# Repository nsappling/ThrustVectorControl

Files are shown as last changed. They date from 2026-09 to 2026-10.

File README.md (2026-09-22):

# Interactive Thrust Vector Control Demonstrator

An interactive senior design project that demonstrates how thrust vector control (TVC) can stabilize a rocket-like body.

Instead of combustion, the system uses an electric ducted fan (EDF) mounted on a **single-axis gimbal**. An inertial measurement unit (IMU) measures the rocket's angle, while a feedback controller redirects the thrust to keep the rocket upright.

The final system is intended to become an interactive science-center exhibit for elementary-school students, families, and school groups.

**Project Status:** Active development. The main concept has been selected, but components and design specifications are still being tested and refined.

## Team.  

- Nate Sapp
- Warren Schindler
- Kailash Gupta-Verma
- Alec Garcia

## Project Goals

Here are our goals:
- Demonstrate thrust vector control in a visible and intuitive way.
- Actively stabilize a rocket-like body about one rotational axis.
- Allow visitors to interact with the system using a joystick.
- Provide immediate visual feedback.
- Be understandable without prior engineering knowledge.
- Operate safely and reliably in a public environment.
- Include a brief explanation for visitors interested in the engineering.
    
## Concept Overview

The demonstrator consists of a lightweight rocket-shaped body mounted to a single-axis pivot. The pivot is positioned below the system's center of gravity, making the rocket naturally unstable.

A gimbaled EDF produces thrust along the rocket's body. A servo rotates the EDF about one axis, changing the direction of the thrust and creating a corrective moment about the pivot.

An IMU continuously measures the rocket's angle and angular velocity. A feedback controller compares the measured angle with the desired angle and adjusts the gimbal to move the rocket toward its target orientation.

The user will interact with the system through a joystick. Depending on the final operating mode, the joystick may command a desired rocket angle, change the thrust level, or apply a temporary disturbance.

## How It Works

1. The IMU measures the rocket's angle and angular velocity.
2. The controller compares the measured angle with the desired angle.
3. A feedback algorithm calculates the required correction.
4. A servo rotates the EDF gimbal.
5. The redirected thrust creates a moment about the pivot.
6. The rocket moves toward the desired orientation.
7. The control loop repeats continuously to maintain stability.

The controller error is defined as:

error = desired angle - measured angle

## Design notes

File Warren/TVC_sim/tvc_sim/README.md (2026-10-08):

# 1-DOF Gimbaled-EDF TVC Demonstrator: MATLAB design simulation

Plain MATLAB (R2019b or newer). No toolboxes needed.

## Quick start
1. Open MATLAB in this folder.
2. Run `tvc_main`. It prints the linear design report, then runs the three demo tests (controller OFF, controller ON, human pilot), plots θ, θ̇, δ, and prints the metrics.
3. Run sections of `tvc_design_sweeps` (Ctrl+Enter inside a `%%` block) for the trade studies.
4. Run `tvc_servo_sizing` for the gimbal servo torque/speed check.

## Files
| File | What it does |
|---|---|
| `tvc_params.m` | **Every number in one place.** Each one is tagged `[EST]`, `[SPEC]`, or `[DES]`. |
| `tvc_simulate.m` | Nonlinear plant (RK4) plus discrete IMU, filter, controller, and servo PWM frame |
| `tvc_scenario.m` | Test definitions: push size/timing, mode, throttle, reference angle |
| `tvc_metrics.m` | Settling time, overshoot, max deviation, steady-state error, gimbal saturation, jitter |
| `tvc_design_gains.m` | PD pole placement: `Kp = (wn² + mgh/I)/(TL/I)`, `Kd = 2ζwn/(TL/I)` |
| `tvc_linear_report.m` | Unstable pole, authority ratio, minimum throttle, latency budget, delay margin, human-delay limit |
| `tvc_design_sweeps.m` | Eight trade studies (see the header of the file) |
| `tvc_servo_sizing.m` | Inertia → acceleration → torque → ×2 margin → candidate torque-speed lines |
| `tvc_animate.m` | Side-view animation of any run |
| `edf_thrust.m` | Thrust vs throttle: power law, or your load-cell table |

## Model
```
I θ̈ = T L sin δ + m g h sin θ − bθ̇ − τc sgn θ̇ + τ_stop + τ_push − I_g δ̈
```
* Servo: position loop, then slew limit, velocity lag, torque limit, gimbal hard stop. It only latches a new command once per PWM frame (50 Hz analog vs 200–333 Hz digital).
* EDF: static map plus first-order spool-up. Throttle can be fixed or `@(t)`.
* IMU: gyro with noise and residual bias. Accelerometer specific force at `r_imu`, including the `rα` and `rω²` motion terms and EDF vibration, so the accelerometer-only angle is realistically wrong.
* Complementary filter, low-pass D-term, one-sample compute delay, command clamp.
* Human pilot: delayed, noisy PD with tremor, for the "why TVC needs a computer" comparison.

Not modeled: fan roll torque and rotor gyroscopic torque. In 1-DOF both act about axes the pivot reacts, so they load the bearings but don't move θ. Also not modeled: thrust loss vs gimbal angle and duct aerodynamics.

## Plugging in real data
* **Thrust stand (Nate):** `p.thrust_table = [u T; ...]`, `p.tau_edf` from a throttle-step test.
* **CAD (Alec/mech):** `p.m`, `p.h_cg`, `p.I`, `p.L`, and `p.Ig` from mass properties.
* **IMU bench (Warren):** `p.gyro_bias`, noise densities, and especially `p.accel_vib` measured with the EDF running.
* **Servo:** step-test it and fit `p.servo_kpos`/`p.servo_tau`. Set `p.servo_refresh` to what it actually accepts.

Then compare the `tvc_simulate` output to logged θ, θ̇, δ from the hardware (the project plan's model-vs-experiment requirement).

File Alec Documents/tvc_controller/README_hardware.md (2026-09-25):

# TVC controller: hardware setup and bench test

`tvc_controller.ino` is the Arduino version (SparkFun RedBoard, Uno-compatible) of the AUTO-mode controller in `rocketgimball.m` / `tvc_sim.m`: the same low-pass filter, PID, ±35° saturation, and fan-tilt sign convention.

## System layout

```
 GY-521 (MPU-6050) --I2C--> RedBoard   --PWM--> 20 kg servo --> fan gimbal
                             |    USB
                        Raspberry Pi 5  (logging, tuning; later: joystick / exhibit UI)
```

- **RedBoard: real-time control.** It runs the loop at 500 Hz with steady timing, which the PID math relies on.
- **Pi 5: supervisor only.** It's connected over USB, logs data, and sends gain changes. It doesn't need to be connected for the controller to run. Don't wire the RedBoard's TX/RX pins directly to the Pi's GPIO: the Pi uses 3.3 V and the RedBoard uses 5 V. USB is simpler and safe.

## Wiring

| From | To | Notes |
|---|---|---|
| GY-521 VCC | 5V | The GY-521 has its own 3.3 V regulator. |
| GY-521 GND | GND | |
| GY-521 SDA | SDA pin (next to AREF) | Internally the same as A4. |
| GY-521 SCL | SCL pin (next to AREF) | Internally the same as A5. |
| Servo signal (orange/yellow) | D4 | Set by `SERVO_PIN`. |
| Servo + (red) | **External 6 V supply +** | 5–7.4 V. It needs about 3 A capacity, since stall current is ~2.5 A. |
| Servo – (brown/black) | External supply – | |
| External supply – | RedBoard GND | **Required.** Without a common ground the servo signal has no reference. |

⚠️ **Never power the servo from the RedBoard's 5V pin.** A 20 kg servo can pull amps when it moves. That will brown out or reset the RedBoard, or damage the USB port or the Pi. Use a 6 V BEC, a bench supply, or a 5 V ≥3 A adapter.

Optionally, put a 470–1000 µF capacitor across the servo supply near the servo to absorb current spikes.

## IMU mounting

Mount the GY-521 with its **Z axis along the rocket's long axis**, chip side facing the nose, so tilting in the gimbal plane rotates the board about its X axis.
- If the gimbal plane lines up with the board's Y axis instead, set `IMU_USE_Y_AXIS = true`.
- Mount it firmly on foam tape or standoffs. Fan vibration is the main noise source for the accelerometer.

## Setup

1. Open `tvc_controller.ino` in the Arduino IDE.
2. Board: **Arduino Uno** (the RedBoard is Uno-compatible). Port: the `usbserial` / CH340 one. If the port does not appear, install the CH340 driver from SparkFun.
3. Check the settings at the top of the sketch:
   - `SERVO_RANGE_DEG`: 180 or 270, depending on your MIUZEI model.
   - `GIMBAL_RATIO`: 1.0 if the servo horn drives the gimbal directly.
4. Upload, then open Serial Monitor at 115200 baud with line ending set to "Newline". Hold the IMU **upright and still** for about 2 s while it calibrates.

## Bench test (no fan): tilt the IMU by hand to fake the body angle

Do these checks **in order**. Keep the fan unpowered.

1. **Angle sign.** Tip the IMU so the rocket's nose leans RIGHT. `theta_deg` should go **positive**, matching MATLAB's convention. If it goes negative, set `IMU_SIGN = -1.0`.
2. **Servo center.** Send `center`. The fan should point straight along the body. If it doesn't, adjust with `trim 20` (µs; try ±values) or re-seat the servo horn. Send `run` to resume.
3. **Servo direction (the critical one).** Lean the nose RIGHT. The fan's **exhaust should swing LEFT**, pointing opposite to the lean. That pushes the tail right and brings the nose back upright. If the exhaust swings the same way as the lean, set `SERVO_DIR = -1.0`. A wrong sign here is positive feedback, and the real rocket will slam into its stops.
4. **Response.** Tip it quickly and hold it. The fan should snap toward full correction. Hold at ~10° for a few seconds: the fan tilt slowly grows as the integral term builds, then caps at ±35°. This is expected, because in the bench test the servo can't actually push the IMU back upright.
5. **Noise.** Hold it still and upright. The fan should sit near 0° with small jitter. Large chatter means you should lower Kd or raise `tau`.

## Tuning from the Pi (or a laptop)

```bash
pip install pyserial
python3 tvc_logger.py
```

Type commands such as `kp 0.5`, `kd 0.035`, `tau 0.02`, `zero`, `center`, `run`, or `help`. They take effect immediately, but aren't saved when the board powers off. Copy any gains you settle on into the sketch.

Each run is saved as `tvc_log_YYYYMMDD_HHMMSS.csv`. To load a log in MATLAB and compare it to the simulation:

```matlab
d = readtable('tvc_log_....csv');
plot(d.t_ms/1000, d.theta_filt_deg)
```

## Differences from the MATLAB sim

| | MATLAB | RedBoard | Why |
|---|---|---|---|
| Angle measurement | `theta + noise` | Complementary filter of gyro + accel (`COMP_TAU` = 0.5 s) | A real sensor needs fusion: the accelerometer is noisy, and the gyro drifts. |
| Loop rate | 2000 Hz physics step | 500 Hz control loop | The gains transfer unchanged because the PID math uses `dt` explicitly. |
| Integral | No limit | Anti-windup: stops growing while the servo is pinned at its limit | Bench testing holds large errors for seconds at a time. |
| Safety | Mechanical stops | Servo centers if the angle is past 45° (resumes automatically below 35°) or the IMU read fails | |
| Servo | Instant | Servo pulse updates at 50 Hz, plus the servo's own speed | Worth adding a servo lag to `tvc_sim.m` later. |

## Before running with the fan

- Measure the real `F_t`, `R`, `m`, and `r_0`. Re-run `tune_pid.m` with those values, then put the new gains in the sketch.
- Secure the fan and add a guard. Have a physical kill switch on the EDF power.

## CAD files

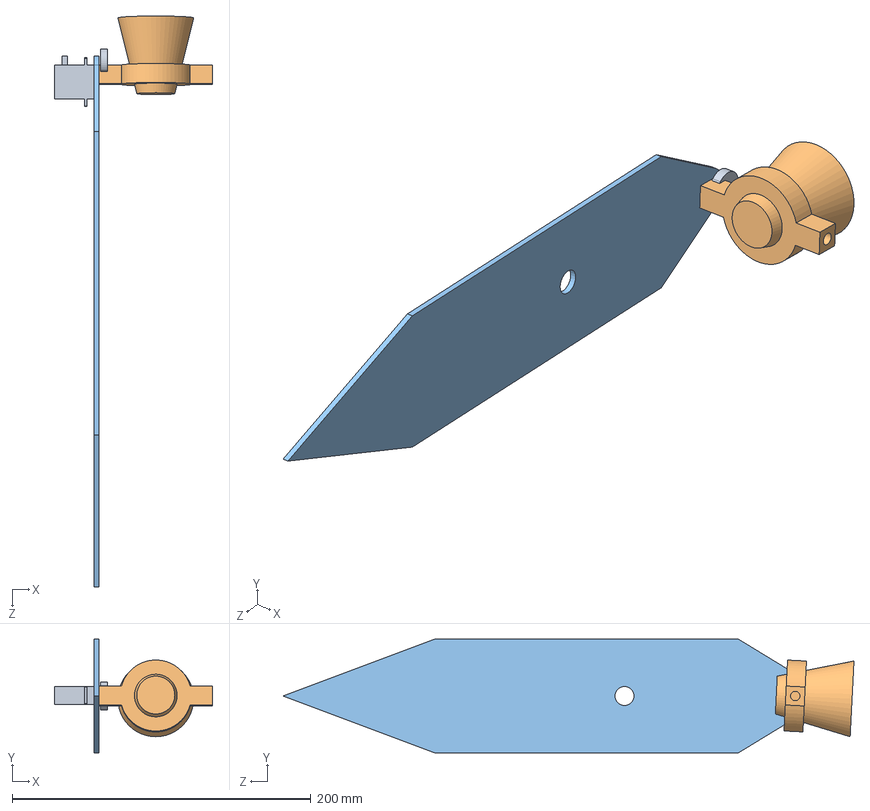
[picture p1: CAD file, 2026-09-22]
Alec Documents/FlatRocketPrototype.SLDASM
106.0 x 76.2 x 382.2 mm
RocketPrototypeFlatBodyPlate
RocketFanforFlatBodyPrototype
BlubirdServocopy

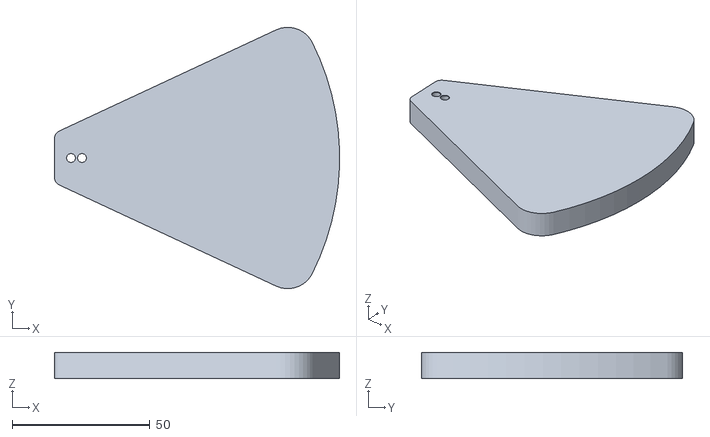
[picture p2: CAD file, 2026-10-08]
3DP Files/EDFMockV2.STL
103.6 x 94.9 x 9.53

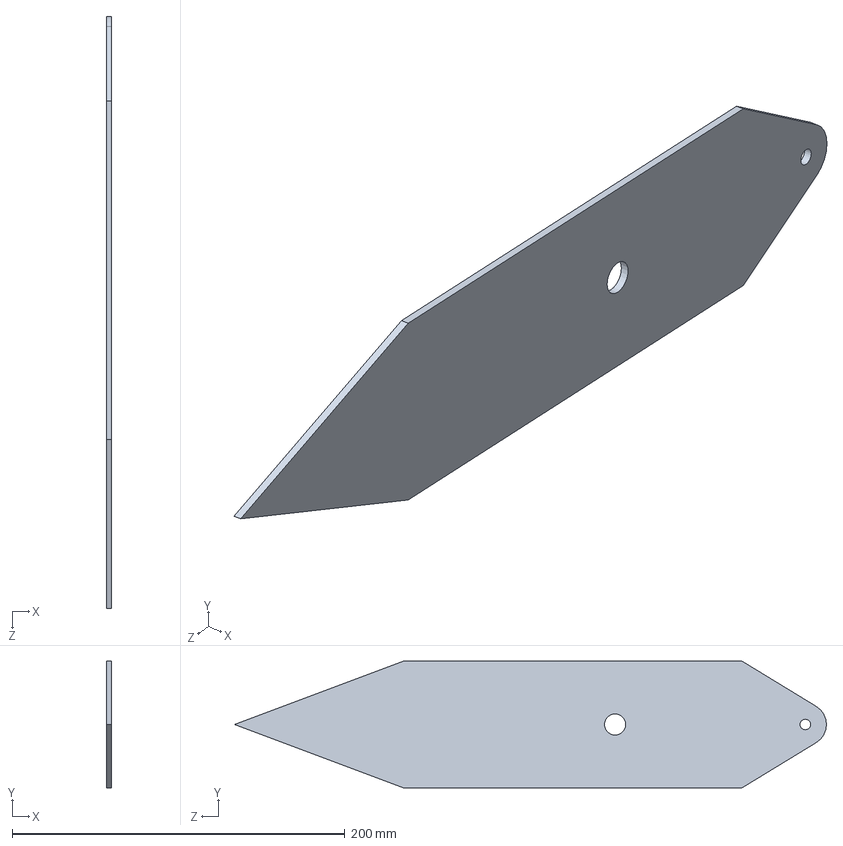
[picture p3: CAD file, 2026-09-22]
Alec Documents/RocketPrototypeFlatBodyPlate.SLDPRT
3.17 x 76.2 x 355.6 mm

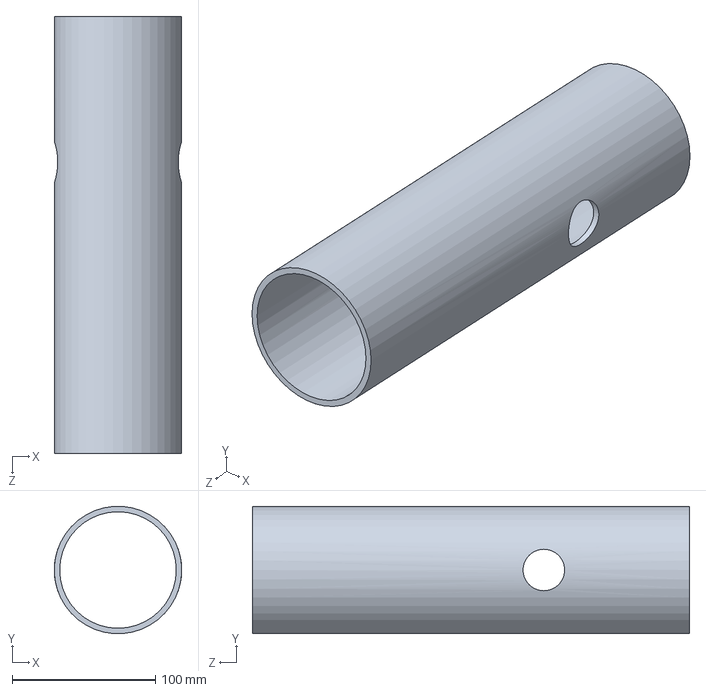
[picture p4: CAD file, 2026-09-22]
Body_Tube.SLDPRT
88.9 x 88.7 x 304.8 mm

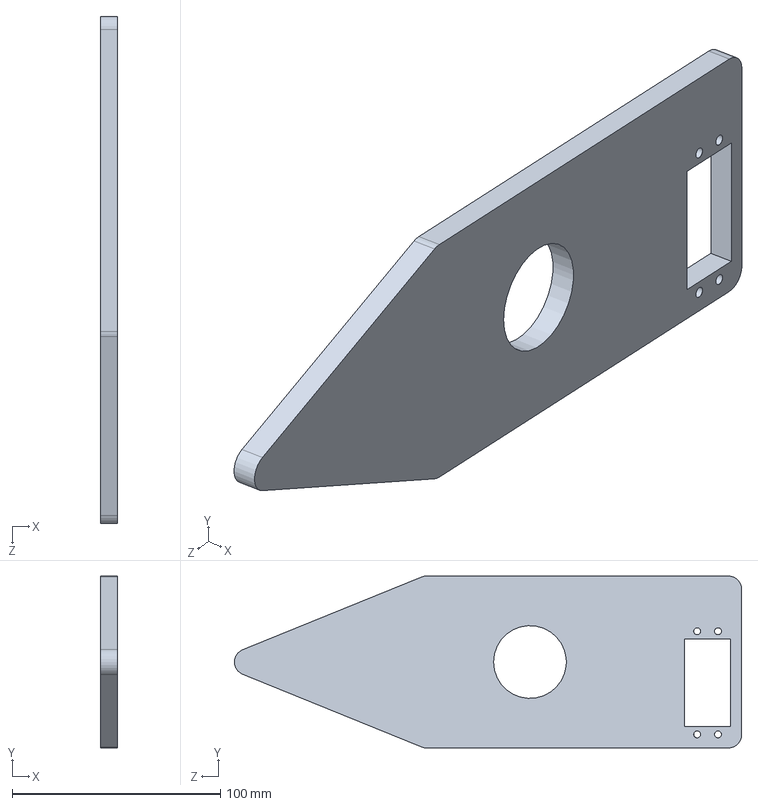
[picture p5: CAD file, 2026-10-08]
Kailash Documents/TVCSimplifiedGimbalPrototype.SLDPRT
8.00 x 82.5 x 243.5 mm

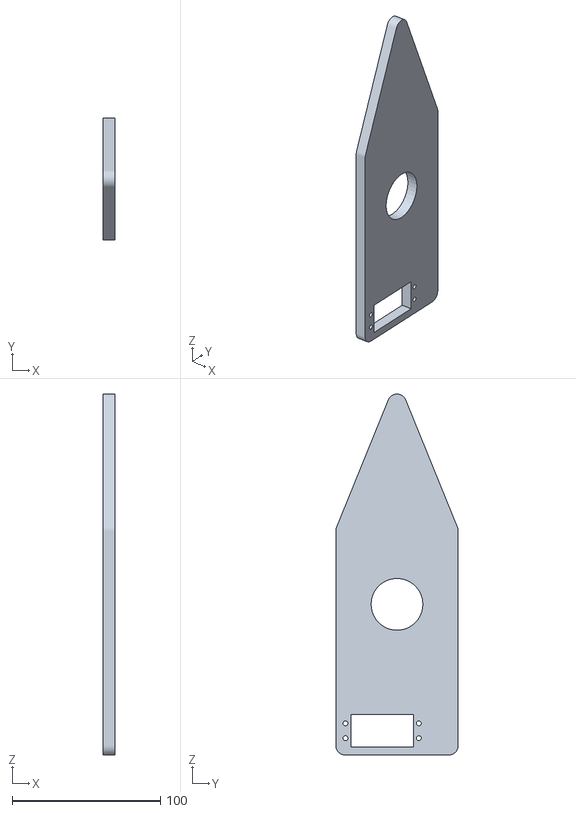
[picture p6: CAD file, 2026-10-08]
3DP Files/BodyPrototypeV2.STL
8.00 x 82.5 x 243.5

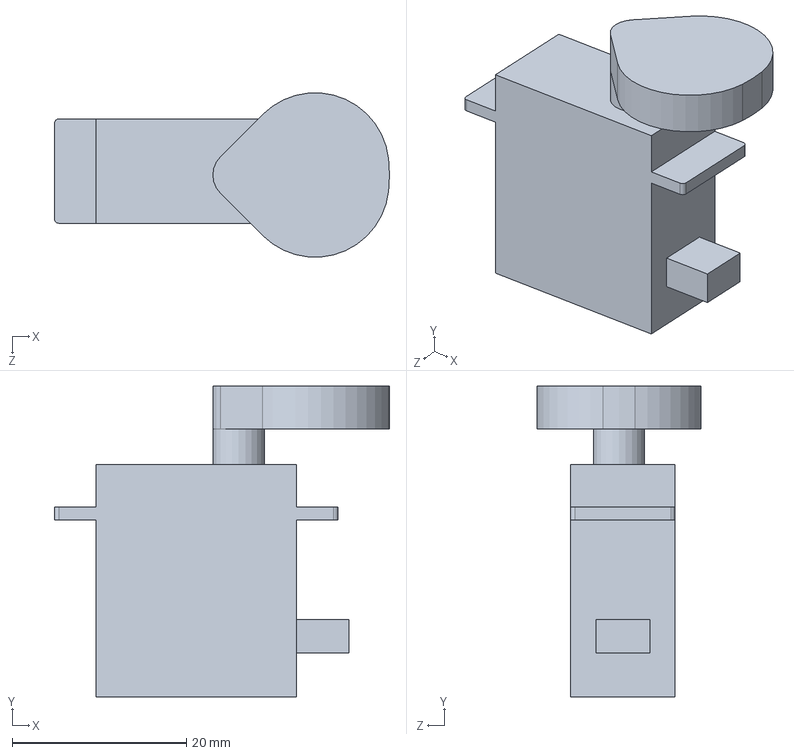
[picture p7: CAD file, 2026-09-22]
Alec Documents/BlubirdServocopy.SLDPRT
38.5 x 35.7 x 18.8 mm

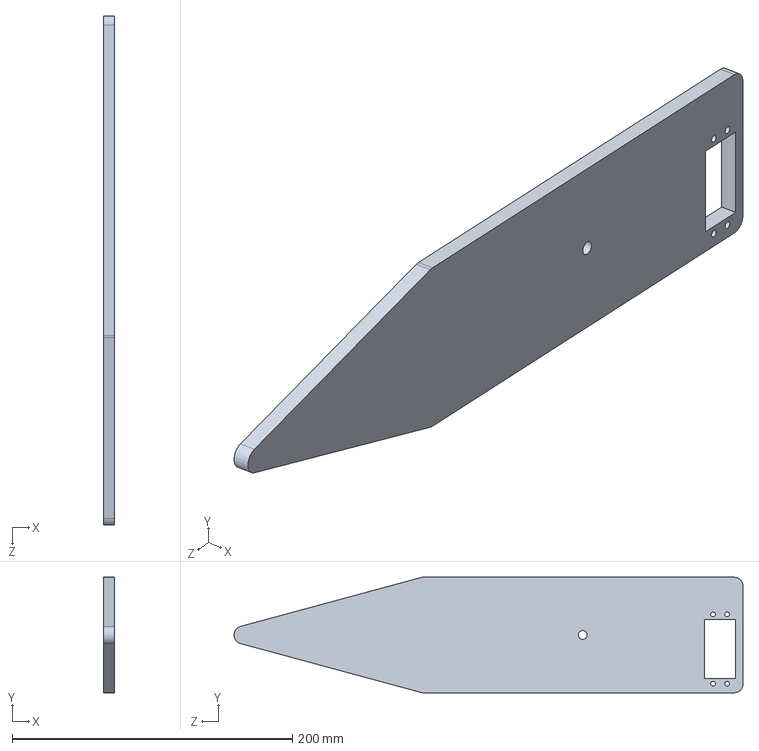
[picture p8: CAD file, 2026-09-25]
Kailash Documents/BodyPrototypeNoHole.SLDPRT
8.00 x 82.5 x 363.1 mm

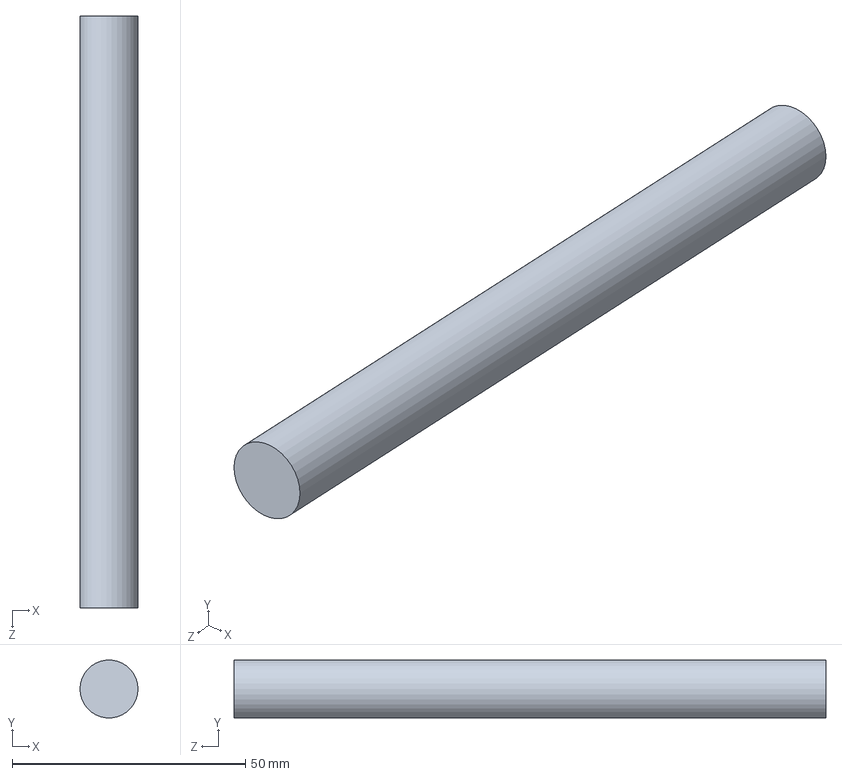
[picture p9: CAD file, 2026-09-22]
Pivot.SLDPRT
12.4 x 12.4 x 127.0 mm

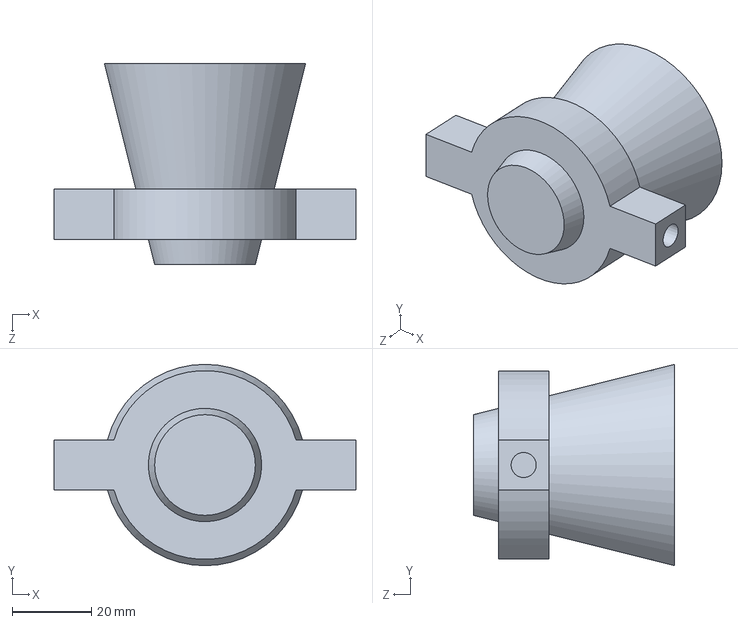
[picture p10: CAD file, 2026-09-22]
Alec Documents/RocketFanforFlatBodyPrototype.SLDPRT
76.2 x 50.8 x 50.8 mm

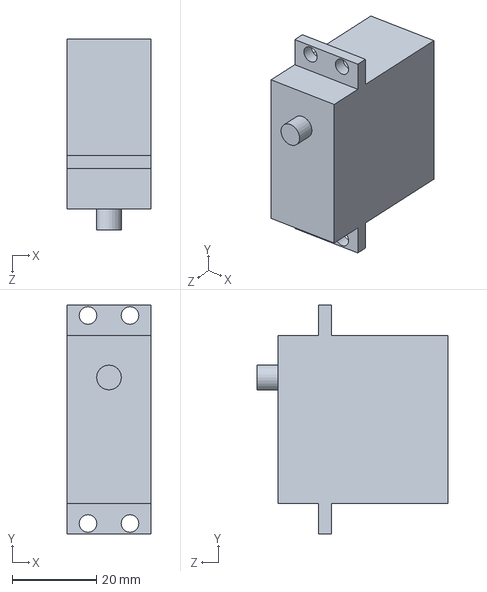
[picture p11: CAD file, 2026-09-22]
Kailash Documents/ServoMotorMockup.SLDPRT
20.0 x 54.5 x 45.5 mm

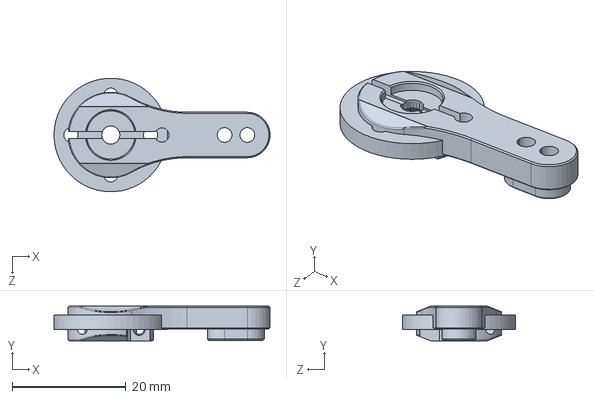
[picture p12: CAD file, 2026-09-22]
Kailash Documents/MotorEndPiece.SLDPRT
38.0 x 6.10 x 19.9 mm

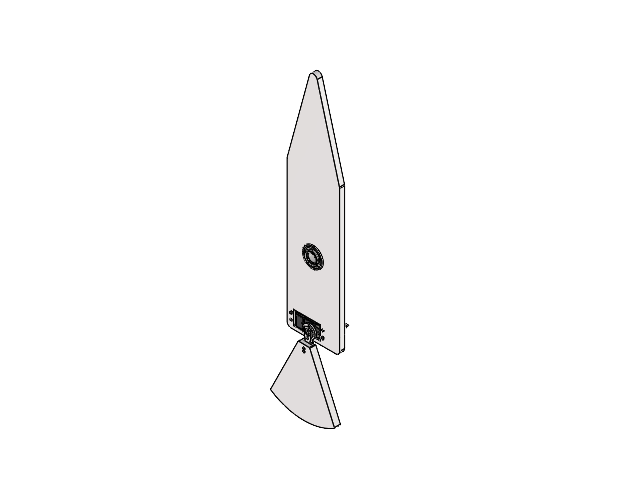
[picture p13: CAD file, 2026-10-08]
Kailash Documents/TVCSimplifiedTLA.SLDASM
TVCSimplifiedGimbalPrototype
6383K234_Steel Ball Bearing
91290A148_Black-Oxide Alloy Steel Socket Head Screw x 2
DS3218MG
EDFMock
MotorEndPiece

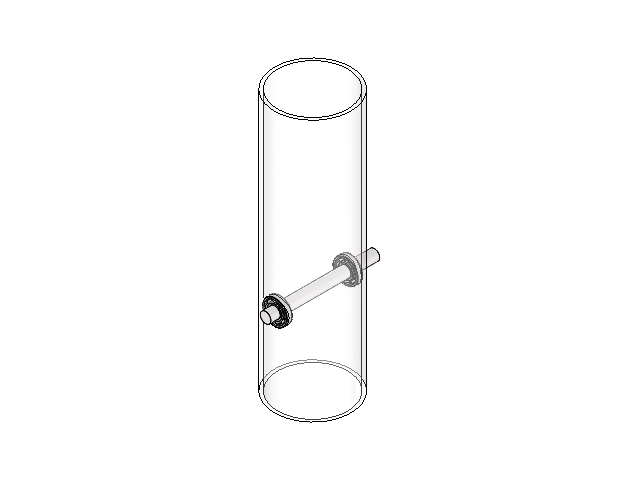
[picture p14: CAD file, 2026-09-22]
Rocket_Assembly.SLDASM
Body_Tube
60355K173_Steel Ball Bearing x 2
Pivot

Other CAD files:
3DP Files/EDFPrototypeMock.STL
3DP Files/BodyPrototypeNoHole.STL
Kailash Documents/EDFMock.SLDPRT
Alec Documents/RocketPrototypeDraft.SLDPRT
60355K173_Steel Ball Bearing.SLDPRT
Kailash Documents/6383K234_Steel Ball Bearing.SLDPRT
Kailash Documents/91290A148_Black-Oxide Alloy Steel Socket Head Screw.SLDPRT
Kailash Documents/DS3218MG.SLDPRT

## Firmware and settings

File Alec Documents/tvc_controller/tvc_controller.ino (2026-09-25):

// tvc_controller.ino
// Arduino (SparkFun RedBoard / Uno-compatible) port of the AUTO-mode controller in rocketgimball.m /
// tvc_sim.m. Reads body angle from a GY-521 (MPU-6050) IMU, runs the
// same low-pass filter + PID, and drives the gimbal servo.
//
// BENCH TEST MODE: no fan needed. Tilt the IMU by hand to "fake" the
// rocket body angle and watch the servo respond. When the IMU is
// finally mounted on the body and the fan is running, this same code
// closes the real loop.
//
// Wiring (see README_hardware.md in this folder for details):
//   GY-521 VCC -> 5V           GY-521 GND -> GND
//   GY-521 SDA -> SDA pin      GY-521 SCL -> SCL pin  (same as A4/A5)
//   Servo signal (orange/yellow) -> D4
//   Servo power (red/brown) -> SEPARATE 6V supply, NOT the board's 5V pin.
//   Tie the supply ground to board GND.
//
// Serial (115200 baud, USB): streams CSV for logging, and accepts
// commands to retune without re-flashing:
//   kp 0.5    ki 0.1    kd 0.035    tau 0.02    zero    center    run    help
//
// No extra libraries needed: Wire and Servo ship with the Arduino IDE.

#include <Wire.h>
#include <Servo.h>

// =====================================================================
// CONTROL PARAMETERS -- same names/meaning as rocketgimball.m
// =====================================================================

float Kp = 0.42, Ki = 0.1, Kd = 0.015;
// PID gains, identical to rocketgimball.m. tune_pid.m suggests
// Kp = 0.5, Kd = 0.035 is more robust to the (still guessed) physical
// parameters -- try it with the "kp"/"kd" serial commands.

float tau_filter = 0.02;       // [s] low-pass filter time constant (same as MATLAB)
const float VIS_SCALE = 200.0; // u -> fan tilt [deg]; also sets Umax (same as MATLAB)
const float fan_tilt_max_deg = 35.0;
const float Umax_actuator = fan_tilt_max_deg / VIS_SCALE;
float ref = 0.0;               // [rad] target angle: upright

const float dt = 0.002;
// [s] control loop period (500 Hz). MATLAB used 0.0005 s, but that was
// a PHYSICS step size -- the PID math uses dt explicitly (integral*dt,
// derivative/dt, alpha from dt) so the gains carry over unchanged.
// 500 Hz leaves plenty of headroom for the I2C read on a 16 MHz ATmega328P.

const float alpha = dt / (tau_filter + dt);
// Discrete low-pass coefficient, same formula as MATLAB. (Recomputed
// in the loop if tau is changed over serial -- see alpha_now.)

const float theta_trip_deg = 45.0;
const float theta_resume_deg = 35.0;
// Safety: if the measured angle is past theta_trip_deg, center the servo
// and stop controlling (the real body should be resting on its stops by
// then). Control resumes AUTOMATICALLY once the angle comes back inside
// theta_resume_deg -- so tilting the IMU too far by hand during bench
// testing no longer leaves the servo stuck until you type 'run'.

// =====================================================================
// HARDWARE CONFIGURATION -- check these against your build
// =====================================================================

const int SERVO_PIN = 4;   // any digital pin works with the Servo library

const float SERVO_RANGE_DEG = 180.0;
// Our MIUZEI 20 kg servo is the 180 degree version (270 degree versions
// also exist). Sets how many microseconds equal one degree.

const int SERVO_MIN_US = 500;
const int SERVO_MAX_US = 2500;
const int SERVO_CENTER_US = 1500;
int servo_trim_us = 0;
// Nudge this if the gimbal isn't straight when the servo is centered
// (use the "center" command, then adjust). Better yet, re-seat the horn.

const float SERVO_DIR = 1.0;
// +1 or -1. Flip if the fan swings the WRONG way in the direction check
// (README_hardware.md). This is the hardware equivalent of MATLAB's
// "b must be positive" -- wrong sign = positive feedback = falls over.

const float GIMBAL_RATIO = 1.0;
// Servo degrees per degree of fan tilt. 1.0 if the horn drives the
// gimbal directly (current design); change if a linkage/gear is added.

// --- IMU axis selection ---
// Mount the GY-521 with its Z axis along the rocket's long axis (chip
// face pointing up when the rocket is upright). Then tilting in the
// gimbal plane is rotation about the IMU's X axis:
//   angle from accel = atan2(ay, az),  rate from gyro = gx
// If your gimbal plane lines up with the IMU's Y axis instead, set
// IMU_USE_Y_AXIS to true (uses atan2(-ax, az) and gy).
const bool IMU_USE_Y_AXIS = false;
const float IMU_SIGN = 1.0;
// +1 or -1: make "nose tips RIGHT" read as POSITIVE theta, to match
// MATLAB's clockwise-positive convention. Check with the serial stream.

const float COMP_TAU = 0.5;
// [s] complementary-filter time constant for fusing gyro + accel into
// an angle. MATLAB didn't need this (it measured theta directly plus
// noise); on real hardware the accelerometer alone is noisy/jerky and
// the gyro alone drifts, so we blend them. Shorter = trusts accel more.

// =====================================================================
// STATE
// =====================================================================

Servo servo;
const uint8_t MPU_ADDR = 0x68;   // GY-521 default (AD0 pin low)

float gyro_bias = 0.0;     // [rad/s] measured at startup
float angle_offset = 0.0;  // [rad] angle reading when held upright at startup
float theta_est = 0.0;     // [rad] complementary-filter angle (the "measured_theta")
float theta_filt = 0.0;    // [rad] after the MATLAB low-pass filter
float integral_term = 0.0;
float prev_error = 0.0;
bool have_prev_error = false;   // MATLAB's prev_error = [] trick
float alpha_now = alpha;
bool running = true;       // false = servo held centered (tripped or "center" command)
bool tripped = false;      // true = paused by the angle limit (auto-resumes); false + !running = "center" command
float u = 0.0;
int servo_us = SERVO_CENTER_US;

unsigned long next_tick_us;
unsigned long tick = 0;
unsigned long imu_errors = 0;   // count of failed IMU reads (reported over serial)

// =====================================================================
// SETUP
// =====================================================================

void setup() {
  Serial.begin(115200);
  Wire.begin();
  Wire.setClock(400000);   // fast I2C so the 14-byte read fits easily in 2 ms
  Wire.setWireTimeout(3000, true);
  // Without a timeout, one electrical glitch on SDA/SCL (servo current
  // spikes, a loose jumper) can freeze the Wire library forever -- the
  // servo then just holds its last position. 3 ms timeout + bus reset.

  servo.attach(SERVO_PIN, SERVO_MIN_US, SERVO_MAX_US);
  servo.writeMicroseconds(SERVO_CENTER_US + servo_trim_us);

  if (!mpu_init()) {
    Serial.println(F("# ERROR: MPU-6050 not found. Check SDA/SCL wiring and power."));
    while (true) {}   // stay here with servo centered
  }

  Serial.println(F("# BOOT (if you see this more than once, the board is resetting -- check servo power)"));
  Serial.println(F("# Hold the IMU/rocket UPRIGHT and STILL -- calibrating..."));
  delay(500);
  calibrate();
  Serial.println(F("# Calibrated."));
  Serial.println(F("t_ms,theta_deg,theta_filt_deg,u,fan_tilt_deg,servo_us"));   // CSV header (log_serial.m uses it)
  Serial.println(F("# Type 'help' for commands."));

  theta_filt = theta_est;
  next_tick_us = micros();
}

// =====================================================================
// MAIN LOOP -- fixed-rate control at 1/dt
// =====================================================================

void loop() {
  handle_serial();

  // Wait for the next tick so dt is really dt (the PID math assumes it).
  if ((long)(micros() - next_tick_us) < 0) return;
  next_tick_us += (unsigned long)(dt * 1e6);

  float acc_angle, gyro_rate;
  if (!read_imu(acc_angle, gyro_rate)) {
    center_servo();   // I2C glitch: fail safe
    // Report glitches (at most once per second) so they show up in logs.
    static unsigned long last_report = 0;
    imu_errors++;
    if (millis() - last_report > 1000) {
      Serial.print(F("# IMU read failed, "));
      Serial.print(imu_errors);
      Serial.println(F(" total -- check SDA/SCL wires, grounds, servo power"));
      last_report = millis();
    }
    return;
  }

  // --- Angle estimate: complementary filter (hardware stand-in for ---
  // --- MATLAB's "measured_theta = theta + noise")                  ---
  const float k = COMP_TAU / (COMP_TAU + dt);
  theta_est = k * (theta_est + gyro_rate * dt) + (1.0 - k) * acc_angle;

  // --- Low-pass filter (same line as MATLAB) ---
  theta_filt = theta_filt + alpha_now * (theta_est - theta_filt);

  // --- Angle limit trip, with automatic resume ---
  if (running && fabs(theta_filt) > radians(theta_trip_deg)) {
    Serial.println(F("# TRIP: angle past limit, servo centered. Resumes when back inside 35 deg."));
    center_servo();
    running = false;
    tripped = true;
  } else if (tripped && fabs(theta_filt) < radians(theta_resume_deg)) {
    Serial.println(F("# Back in range, control resumed."));
    running = true;
    tripped = false;
    integral_term = 0;         // start fresh, don't carry old error history
    have_prev_error = false;
  }

  if (running) {
    // --- PID controller (same as MATLAB) ---
    float error = ref - theta_filt;
    if (!have_prev_error) {
      prev_error = error;      // avoid a derivative-kick on the very first sample
      have_prev_error = true;
    }
    float derivative = (error - prev_error) / dt;
    prev_error = error;

    // Anti-windup (NOT in the MATLAB sim): only let the integral grow
    // while the actuator is NOT already pinned at its limit in the same
    // direction. Otherwise, holding the IMU tilted on the bench (where
    // the servo can't move it back) fills the integral up, and the servo
    // stays stuck at full tilt for seconds after you tilt back.
    float u_try = Kp * error + Ki * (integral_term + error * dt) + Kd * derivative;
    bool pinned = (u_try > Umax_actuator && error > 0) || (u_try < -Umax_actuator && error < 0);
    if (!pinned) integral_term += error * dt;
    if (Ki > 0) integral_term = constrain(integral_term, -Umax_actuator / Ki, Umax_actuator / Ki);

    u = Kp * error + Ki * integral_term + Kd * derivative;

    // --- Actuator saturation (same as MATLAB) ---
    u = constrain(u, -Umax_actuator, Umax_actuator);

    // --- u -> fan tilt, same sign convention as rocketgimball.m's drawing ---
    float fan_tilt_deg = constrain(-u * VIS_SCALE, -fan_tilt_max_deg, fan_tilt_max_deg);
    write_servo(fan_tilt_deg);
  }

  // --- Log at 50 Hz (every 10th tick) so the serial link keeps up ---
  if (++tick % 10 == 0) {
    Serial.print(millis());                     Serial.print(',');
    Serial.print(degrees(theta_est), 2);        Serial.print(',');
    Serial.print(degrees(theta_filt), 2);       Serial.print(',');
    Serial.print(u, 4);                         Serial.print(',');
    Serial.print(-u * VIS_SCALE, 1);            Serial.print(',');
    Serial.println(servo_us);
  }
}

// =====================================================================
// SERVO
// =====================================================================

void write_servo(float fan_tilt_deg) {
  const float us_per_deg = (SERVO_MAX_US - SERVO_MIN_US) / SERVO_RANGE_DEG;
  float servo_deg = SERVO_DIR * GIMBAL_RATIO * fan_tilt_deg;
  servo_us = SERVO_CENTER_US + servo_trim_us + (int)(servo_deg * us_per_deg);
  servo_us = constrain(servo_us, SERVO_MIN_US, SERVO_MAX_US);
  servo.writeMicroseconds(servo_us);
}

void center_servo() {
  u = 0.0;
  servo_us = SERVO_CENTER_US + servo_trim_us;
  servo.writeMicroseconds(servo_us);
}

// =====================================================================
// IMU (MPU-6050 over raw I2C -- no library needed)
// =====================================================================

void mpu_write(uint8_t reg, uint8_t val) {
  Wire.beginTransmission(MPU_ADDR);
  Wire.write(reg);
  Wire.write(val);
  Wire.endTransmission();
}

bool mpu_init() {
  Wire.beginTransmission(MPU_ADDR);
  if (Wire.endTransmission() != 0) return false;
  mpu_write(0x6B, 0x01);   // PWR_MGMT_1: wake up, use gyro X clock
  mpu_write(0x1A, 0x02);   // CONFIG: digital low-pass ~94 Hz (~3 ms delay)
  mpu_write(0x1B, 0x08);   // GYRO_CONFIG: +/-500 deg/s  (65.5 LSB per deg/s)
  mpu_write(0x1C, 0x08);   // ACCEL_CONFIG: +/-4 g      (8192 LSB per g)
  delay(100);
  return true;
}

// Returns the accelerometer tilt angle [rad] and gyro rate [rad/s] for
// the gimbal axis, with sign/offset/bias corrections applied.
bool read_imu(float &acc_angle, float &gyro_rate) {
  Wire.beginTransmission(MPU_ADDR);
  Wire.write(0x3B);   // ACCEL_XOUT_H: read accel(6) + temp(2) + gyro(6)
  if (Wire.endTransmission(false) != 0) return false;
  if (Wire.requestFrom(MPU_ADDR, (uint8_t)14) != 14) return false;

  int16_t raw[7];
  for (int i = 0; i < 7; i++) raw[i] = (Wire.read() << 8) | Wire.read();
  float ax = raw[0], ay = raw[1], az = raw[2];   // units cancel in atan2
  float gx = raw[4] / 65.5, gy = raw[5] / 65.5;  // deg/s

  float a_raw, g_raw;
  if (IMU_USE_Y_AXIS) { a_raw = atan2(-ax, az); g_raw = radians(gy); }
  else                { a_raw = atan2(ay, az);  g_raw = radians(gx); }

  // Wrap the difference into -180..+180 deg. atan2 jumps from +180 to
  // -180 at one orientation; without this, crossing it would look like a
  // sudden 360 degree tilt (-> servo slam / trip).
  float d = a_raw - angle_offset;
  if (d > PI) d -= 2 * PI;
  if (d < -PI) d += 2 * PI;
  acc_angle = IMU_SIGN * d;
  gyro_rate = IMU_SIGN * (g_raw - gyro_bias);
  return true;
}

// Average readings while held still and upright: sets the gyro bias and
// defines "upright" as the current orientation (so the IMU doesn't need
// to be mounted perfectly straight).
void calibrate() {
  angle_offset = 0; gyro_bias = 0;
  const int N = 500;
  float a_sum = 0, g_sum = 0, a, g;
  int got = 0;
  for (int i = 0; i < N; i++) {
    if (read_imu(a, g)) { a_sum += a; g_sum += g; got++; }
    delay(2);
  }
  if (got == 0) return;
  // read_imu applied IMU_SIGN; undo it so the offsets are in raw units
  angle_offset = IMU_SIGN * a_sum / got;
  gyro_bias = IMU_SIGN * g_sum / got;
  theta_est = 0;
  integral_term = 0;
  have_prev_error = false;
}

// =====================================================================
// SERIAL COMMANDS (from Serial Monitor or the Pi)
// =====================================================================

void handle_serial() {
  static char buf[32];
  static uint8_t n = 0;
  while (Serial.available()) {
    char c = Serial.read();
    if (c == '\n' || c == '\r') {
      if (n > 0) { buf[n] = 0; run_command(buf); n = 0; }
    } else if (n < sizeof(buf) - 1) {
      buf[n++] = c;
    }
  }
}

void run_command(char *cmd) {
  char *arg = strchr(cmd, ' ');
  float val = 0;
  if (arg) { *arg = 0; val = atof(arg + 1); }

  if      (!strcmp(cmd, "kp") && arg)  Kp = val;
  else if (!strcmp(cmd, "ki") && arg)  { Ki = val; integral_term = 0; }
  else if (!strcmp(cmd, "kd") && arg)  Kd = val;
  else if (!strcmp(cmd, "tau") && arg) { tau_filter = val; alpha_now = dt / (tau_filter + dt); }
  else if (!strcmp(cmd, "trim") && arg) servo_trim_us = (int)val;
  else if (!strcmp(cmd, "zero"))   { center_servo(); calibrate(); theta_filt = 0; Serial.println(F("# Re-zeroed.")); }
  else if (!strcmp(cmd, "center")) { running = false; tripped = false; center_servo(); Serial.println(F("# Servo centered, control paused. 'run' to resume.")); }
  else if (!strcmp(cmd, "run"))    { running = true; tripped = false; integral_term = 0; have_prev_error = false; Serial.println(F("# Running.")); }
  else if (!strcmp(cmd, "help")) {
    Serial.println(F("# kp/ki/kd/tau <val>, trim <us>, zero (hold upright+still), center, run"));
  } else {
    Serial.println(F("# Unknown command. Type 'help'."));
    return;
  }
  Serial.print(F("# Kp=")); Serial.print(Kp, 4);
  Serial.print(F(" Ki=")); Serial.print(Ki, 4);
  Serial.print(F(" Kd=")); Serial.print(Kd, 4);
  Serial.print(F(" tau=")); Serial.print(tau_filter, 4);
  Serial.print(F(" trim=")); Serial.println(servo_trim_us);
}

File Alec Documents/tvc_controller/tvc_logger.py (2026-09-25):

#!/usr/bin/env python3
"""tvc_logger.py -- run on the Raspberry Pi (or any laptop) with the RedBoard
plugged in over USB.

Saves the RedBoard's CSV stream to a timestamped file (open it in MATLAB with
readtable) and lets you type tuning commands (kp 0.5, kd 0.035, zero,
center, run, help) that get sent straight to the RedBoard.

    pip install pyserial
    python3 tvc_logger.py                 # auto-picks the port
    python3 tvc_logger.py /dev/ttyUSB0    # or name it explicitly

Ctrl+C to quit.
"""
import sys
import threading
import time
from datetime import datetime

import serial
from serial.tools import list_ports

BAUD = 115200
HEADER = "t_ms,theta_deg,theta_filt_deg,u,fan_tilt_deg,servo_us"


def find_port():
    for p in list_ports.comports():
        # RedBoard / clones show up as CH340 (ttyUSB*), genuine Arduinos as ACM
        if any(s in (p.device + str(p.description)) for s in ("USB", "ACM", "usbserial", "CH340")):
            return p.device
    sys.exit("No Arduino found -- pass the port name, e.g. /dev/ttyUSB0")


def reader(ser, f):
    last_print = 0.0
    while True:
        line = ser.readline().decode(errors="replace").strip()
        if not line:
            continue
        if line.startswith("t_ms"):
            continue                         # board's own CSV header (already written above)
        if line.startswith("#"):
            print(line)                      # status messages from the board
            continue
        f.write(line + "\n")
        now = time.time()
        if now - last_print > 0.5:           # don't flood the terminal
            parts = line.split(",")
            if len(parts) == 6:
                print(f"  theta={parts[2]:>7} deg   fan={parts[4]:>6} deg   servo={parts[5]} us")
            last_print = now


def main():
    port = sys.argv[1] if len(sys.argv) > 1 else find_port()
    fname = datetime.now().strftime("tvc_log_%Y%m%d_%H%M%S.csv")
    ser = serial.Serial(port, BAUD, timeout=1)
    print(f"Connected to {port}. Logging to {fname}. Type commands, Ctrl+C to quit.")
    with open(fname, "w", buffering=1) as f:
        f.write(HEADER + "\n")
        threading.Thread(target=reader, args=(ser, f), daemon=True).start()
        try:
            while True:
                cmd = input()
                ser.write((cmd.strip() + "\n").encode())
        except (KeyboardInterrupt, EOFError):
            print(f"\nSaved {fname}")


if __name__ == "__main__":
    main()

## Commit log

2026-09-22 Equations, preliminary bearings/pivot concept
    [60355K173_Steel Ball Bearing.SLDPRT, Body_Tube.SLDPRT, Pivot.SLDPRT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]
2026-09-22 Added alecs cad drafts
    [BlubirdServocopy.SLDPRT, FlatRocketPrototype.SLDASM, RocketFanforFlatBodyPrototype.SLDPRT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]
2026-09-22 Cadded out the super basic prototype with a ServoMotor
    [6383K234_Steel Ball Bearing.SLDPRT, 91290A148_Black-Oxide Alloy Steel Socket Head Screw.SLDPRT, DS3218MG.SLDPRT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]
2026-09-25 Made STL files for printing
    [6383K234_Steel Ball Bearing.SLDPRT, 91290A148_Black-Oxide Alloy Steel Socket Head Screw.SLDPRT, BodyPrototypeNoHole.SLDPRT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]
2026-10-08 Adding CAD drawings for prototype
    [BodyPrototypeV2.STL, EDFMockV2.STL, TVCSimplifiedGimbalPrototype.SLDPRT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]
2026-10-11 Reorganize repo by function instead of by person
    - firmware/: tvc_controller (main loop) and tests/ (hardware_test,
    RotationMappedToServoTest)
    - ground/: tvc_logger.py (Pi side)
    - sim/: tvc_sim (Warren's design sim), pid_animation (Alec's PID sim)
    - cad/: each assembly kept together with its parts so SolidWorks
    references still resolve; STLs in cad/stl
    - docs/: initial system sketch
    - Root CLAUDE.md replaces Alec Documents/CLAUDE.md; short README per folder
    - .gitignore (drops .DS_Store, logs) and .gitattributes (CAD as binary)
    - Fixed path references in tune_pid.m, log_serial.m, and the controller README
    Claude-Session: https://cl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
2026-10-11 Add preliminary electrical docs, wiring harness, and Teensy firmware skeleton
    Docs (docs/):
    - system_overview.md: block diagram, power budget, ground scheme, key
    decisions, open items
    - components.md: specs and sources for PSU, ESC, EDF, HTD-30H, BusLinker,
    GY-521, Teensy 4.0, Pi 5, wiring; unconfirmed values tagged [VERIFY]
    - pinout.md: Teensy pin assignments (single source of truth)
    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
2026-10-11 Add blank Python script ground/new_script.py
    Empty placeholder file; no code, nothing to test on hardware.
    Claude-Session: https://claude.ai/code/session_014xG5YAh1ZCfuyMfPc3EgKE
2026-10-12 some more simulation updates to reflect more realistic moment of inertia (uniform cylinder)
2026-10-16 EDF prototype assembly cad
2026-10-16 Add design_justification.md: selection considerations for every component
    Docs only. Records the HTD-85H as the current servo pick (it replaced the
    HTD-30H on sustained torque) and flags open questions: HTD-85H stall current
    vs the 5 A fuse, and the sim's ~0.2 N·m vs the 3 N·m gimbal torque target.
    Claude-Session: https://claude.ai/code/session_01Y8LurgLbwrybHG2spuFSkp
2026-10-16 design_justification: HTD-30H is the chosen servo (docs only)
    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
2026-10-16 Changes to edf prototype. added the servo to edf connection
2026-10-16 Made the mounting adapter
2026-10-16 finished first version of edf and servo couplings and created stl files to 3d print
2026-10-21 esc_test: non-blocking rewrite for Teensy 4.0/4.1 with ramp and auto-stops
    Rewrites the ESC bring-up sketch so the loop never blocks on serial input:
    - holds 1000 us for 3 s at boot so the ESC arms
    - throttle ramps up at 0.2/s, stops instantly; still capped at 0.30
    - auto-stop on USB serial loss, on any unrecognized command, and after
    30 s without a new 't' command
    - calibration is a step-by-step state machine; any unexpected input aborts
    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
2026-10-21 Switch flight computer target from Teensy 4.0 to Teensy 4.1 (docs + labels)
    The team is using a Teensy 4.1. Pins 0-23 are in the same places with the
    same functions on both boards, so no pin assignments change; this is a
    relabel only:
    - docs (pinout, system overview, components, design justification,
    servo_bus ICD), READMEs, CLAUDE.md, code comments
    - compile FQBN teensy:avr:teensy40 -> teensy:avr:teensy41
    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
2026-10-21 cad/README: list the edf_coupling_prototype folder (docs only)
    Claude-Session: https://claude.ai/code/session_014pc9KmBLtXpGH2Y2KkDEyA
2026-10-21 Got the EDF & ESC working
2026-10-21 Got the servo & hiwonder working with Teensy
2026-10-23 Move servo bus UART from Serial1 (pins 0/1) to Serial2 (pins 7/8)
    Matches the wiring that works on the bench (Kailash's
    ServoHiwonderKeyboardControlBringupTest, confirmed by Alec):
    Teensy pin 8 (TX2) -> BusLinker RX
    Teensy pin 7 (RX2) <- BusLinker TX
    ESC signal stays on pin 2.
    Updated together per CLAUDE.md: config.h (SERVO_BUS_SERIAL = Serial2),
    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
2026-10-23 Add imu_servo_follow: gimbal servo mirrors the IMU tilt one to one
    New bring-up sketch (firmware/tests/imu_servo_follow). Reads the MPU-6050
    directly over I2C (pins 18/19), fuses gyro + accel with a complementary
    filter, and sends the HTD-30H a move every 20 ms through the BusLinker on
    Serial2 (pins 7/8), reusing the move packet from Kailash's
    ServoHiwonderKeyboardControlBringupTest. At startup (held upright and
    still) it measures gyro bias, auto-detects the IMU's up axis and takes
    the current tilt as zero. Servo range clamped to 350-650 counts (~+/-36
    deg). Serial commands: z re-zero, h hold, g go, s swap direction.
    Compiled for Teensy 4.1 against the Teensy core sources; axis/gyro-sign
    lo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
2026-10-23 imu_servo_follow: live center trim (+/- 1 count, ]/[ 10 counts)
    Servo position 500 is not where the fan points straight. The follow
    sketch now keeps a live center that can be nudged from the Serial
    Monitor while holding (h), prints the result, and clamps travel to
    +/-150 counts around that center instead of fixed 350..650. Copy the
    found value into SERVO_CENTER.
    Compiled for Teensy 4.1. Not tested on hardware.
    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
2026-10-23 Ramp EDF throttle down to stop the PSU's overvoltage trip
    The Mean Well shut off and stayed off during ESC tests. Likely cause
    (not yet measured): cutting throttle instantly makes the fan regenerate
    into the 12 V bus, which the PSU can't absorb, so its overvoltage
    protection latches it off.
    - esc_test: throttle now ramps DOWN at 0.15/s (2 s from the 0.30 cap).
    's', unrecognized lines and the run-time limit ramp down; new 'x' is
    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
2026-10-23 Integrated code for ramping throttle and integrating EDF, servo, and gyro
2026-10-27 Tons of prototype CAD progress
2026-10-28 made copy to start enclosure EDF mount
2026-11-04 Finalizing prototype CAD
2026-11-04 more CAD
2026-11-13 Wiring rev B: document as-built (no level shifter, IMU INT unused)
    - Harness: removed the BSS138 shifter; BusLinker TX/RX/GND wired straight to
    Teensy pins 7/8/GND. IMU INT and AD0 marked not connected. Teensy VIN unused.
    - servo_bus ICD: new check for BusLinker TX voltage into Teensy pin 7, with a
    1k/2k divider fix if it measures ~5 V.
    - pinout, imu_i2c, system_overview, components, design_justification,
    CLAUDE.md, and code comments updated to match.
    Docs and comments only; no code logic changed.
    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
